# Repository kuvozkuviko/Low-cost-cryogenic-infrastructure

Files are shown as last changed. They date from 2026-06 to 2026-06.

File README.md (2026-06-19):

# Low-Cost Cryogenic Infrastructure

**EPFL Quantum Science and Engineering — Semester Project 2025–2026**  
**Author:** Andrés Quesnel González  
**Supervisor:** Dr. Gregor Taylor  
**Professor:** Prof. Edoardo Charbon

A low-cost cryogenic temperature readout system based on the Lake Shore Cryotronics DT-670 silicon diode and a thermal load measurement PCB for characterising the heat dissipation of 
cryogenic electronics.

---

## Overview

The system provides a stable 10 µA excitation current to a DT-670 silicon diode, reads the resulting voltage with a 24-bit ADC, converts it to temperature using the manufacturer's calibration 
table, and displays the result on two 7-segment displays. It was validated by monitoring the 4 K and 40 K stages of a Photon Spot Cryospot 4 over 24 hours.

The companion thermal load PCB uses a 1 kΩ thin-film resistor as a controllable heat source to establish a calibration curve of the cryocooler's cooling capacity as a function of temperature. 
This curve can then be used to quantify the thermal impact of any electronics placed inside the cryostat.

---

## Hardware

### Temperature Readout PCB

A custom PCB (60 × 35 mm) that drives a DT-670 silicon diode with a stable 10 µA constant current and reads its voltage response via a 24-bit ADS1220 ADC. 
The converted temperature is shown on two Grove 4-digit 7-segment displays connected to an Arduino UNO R4 WiFi.

**Key components:**

| Component | Part | Purpose |
|---|---|---|
| Voltage shunt regulator | LM4041-N ADJ | Precision 1.225 V reference |
| Transistor array | THAT 320S14-U | PNP current source with thermal compensation |
| Sensing resistor | TNPW0603 66.5 kΩ (0.1%, 10 PPM/°C) | Sets output current to 10 µA |
| ADC | ADS1220 | 24-bit, 596 nV resolution with 5 V reference |
| Voltage regulator | LM78L05 | 5 V regulated supply from 12 V lab rail |
| Microcontroller | Arduino UNO R4 WiFi | Reads ADC via SPI, drives displays |
| Displays | Grove 4-digit 7-segment (TM1637) | Shows temperature in kelvin |
| Connector | L17HTNES4R2C (Amphenol, right-angle DB-9) | Interfaces with cryostat wiring |

**Temperature resolution:**  
20 µK at 4 K · 259 µK at 300 K  
(24-bit ADC at 5 V reference, diode sensitivity from Table 2 of the report)

**Total system cost: CHF 273.26**

### Thermal Load PCB

A minimal PCB (16.24 × 15.26 mm) with a single 1 kΩ thin-film resistor, M3 mounting hole, and 4-pin through-hole connector for 4-wire SMU connection. 
It attaches to the PCB under test on one side and to a copper puck on the other.

---

## Getting Started

### Arduino Firmware

#### Requirements

- Arduino IDE 2.x or later
- Libraries (install via Library Manager):
  - `ADS1220_WE` by Wolfgang Ewald
  - `TM1637Display` by Avishay Orpaz

#### Wiring

| ADS1220 pin | Arduino UNO R4 pin |
|---|---|
| CS | 7 |
| DRDY | 6 |
| SCLK | 13 (SPI SCK) |
| DIN | 11 (SPI MOSI) |
| DOUT | 12 (SPI MISO) |

| Display | CLK | DIO |
|---|---|---|
| Sensor 1 (4 K stage) | 2 | 3 |
| Sensor 2 (40 K stage) | 4 | 5 |

---

### Python — Data Acquisition

Reads the Arduino's serial output and saves it to a CSV file.

#### Requirements

```
pip install pyserial
```

#### Usage

```bash
python code/data_Sidiode.py --port /dev/ttyUSB0 --output CSVs/andres_2_06_log_temperaturereadout.csv
```

Arguments:
- `--port`: Serial port the Arduino is connected to (e.g. `COM3` on Windows, `/dev/ttyACM0` on Linux)
- `--output`: Path to the output CSV file
- `--baud`: Baud rate (default: 9600)

Output CSV format:
```
time_ms, T1_K, T2_K
1204, 3.214823, 32.771456
...
```

---

### Python — Analysis and Plotting

#### Requirements

```
pip install numpy pandas matplotlib scipy
```

#### Temperature curves (RT measurement)

```bash
python Code/Sidiode_plot.py --input CSVs/andres_2_06_log_temperaturereadout.csv
```

Produces a plot of temperature vs time for both stages, equivalent to Figure 8 in the report.

#### Thermal load calibration curves

```bash
python python/analysis/plot_heatload.py \
    --smooth data/heatload_smooth.csv \
    --coarse data/heatload_coarse.csv
```

Produces the three-panel plot (Figure 9 in the report): measured power vs temperature, power difference vs temperature, and cryogenic resistance R(T).

Input CSV format (from the AQUA lab measurement script):
```
Time [s], T [K], Current [A], Voltage [V], Power [mW], Resistance [Ohm]
```

---

## Mechanical

`Thermal Load/CopperPuck-Body.step` is the STEP file for the copper puck used to absorb heat on the back side of the thermal load PCB when it is mounted inside the cryostat. Import into FreeCAD, Fusion 360, or any STEP-compatible CAD tool.

---

## SPICE Simulation

`Temperature Readout/Simu_SiDiode670.asc` is the LTspice XVII simulation of the LM4041-N ADJ constant current source. It was used to verify that the output current is independent of the biasing current and to compare the performance of the 120 kΩ and 122.5 kΩ sensing resistor values.

Open with LTspice XVII (free, from Analog Devices).

---

## Bill of Materials

| Item | Cost (CHF) |
|---|---|
| PCB fabrication (Eurocircuits) | 200.00 |
| Arduino UNO R4 WiFi | 23.70 |
| 2× Grove 7-segment displays | 13.77 |
| Display cables | 1.10 |
| Stripboard | 5.10 |
| Aluminium enclosure (Hammond) | 25.30 |
| **Total** | **269.97** |

---

## Known Issues and Future Work

- The 66.5 kΩ sensing resistor was hand-soldered to replace the original 120 kΩ value. The solder joints are visually imperfect and the output current may deviate slightly from the target 10 µA, introducing a small systematic temperature offset.
- The DB-9 connector pin ordering on the original PCB was incorrect and was corrected with a wired adapter. A future PCB revision should use the correct pinout directly.
- The ADS1220 is configured with a 5 V external reference (REFP0 = 5 V), giving 596 nV resolution. Using the internal 2.048 V reference would improve resolution to 244 nV, since the DT-670 voltage never exceeds 1.644 V.
- Two-minute dwell times between thermal load current steps were insufficient for full thermal equilibration. Future measurements should use at least 5 minutes per step.
- The thermal load calibration was performed with the PCB under test powered off. A future measurement with the PCB powered will yield its actual heat dissipation.

---

## Related Files

The full semester project report (`TP4_spring_2026.pdf`) is included at the root of this repository and contains the full circuit analysis, component selection rationale, measurement results, and discussion.

---

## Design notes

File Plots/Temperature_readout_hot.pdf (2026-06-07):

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

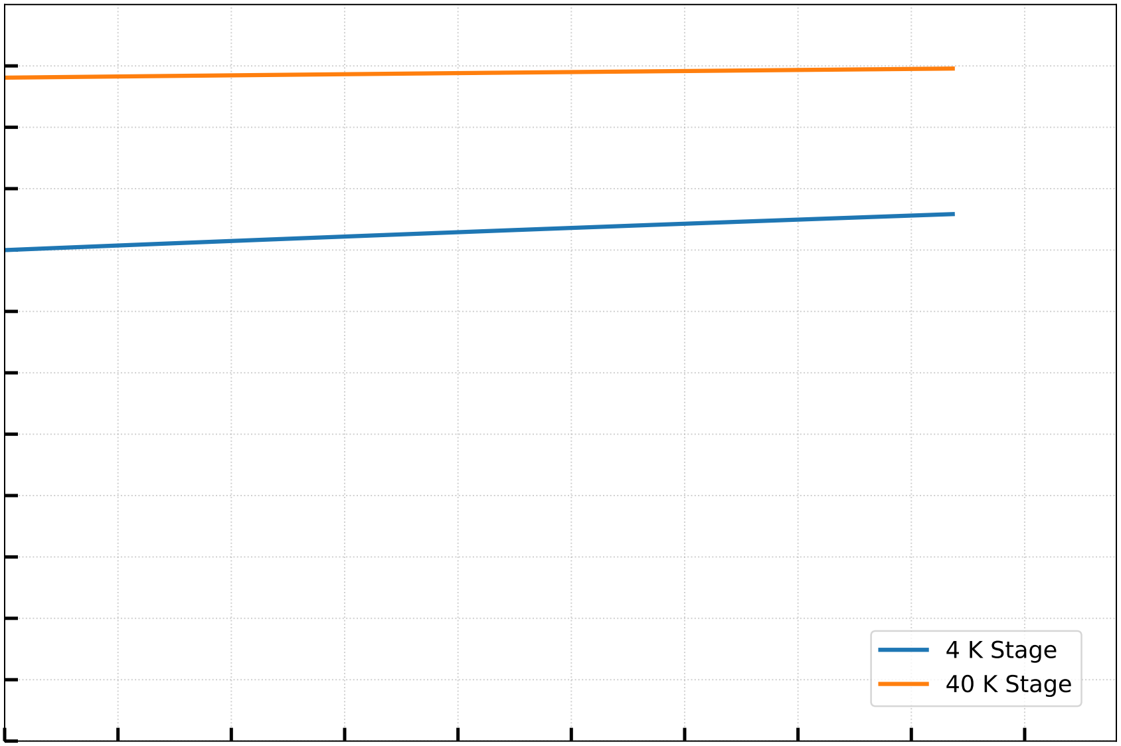
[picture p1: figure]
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

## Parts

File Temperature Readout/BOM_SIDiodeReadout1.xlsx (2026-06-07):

Qty | Reference Designators | Value | Package | Manufacturer | MPN | Placed
2 | U1, U2 | LM4041AIM3-1.2 | SOT-23 | Texas Instruments | LM4041AIM3-1.2 | YES
1 | U3 | LM78L05ACM/NOPB | SOIC-8 | Texas Instruments | LM78L05ACM/NOPB | YES
1 | IC1 | 320S14-U | SOIC-14 | THAT Corporation | 320S14-U | YES
1 | IC2 | ADS1220IPW | TSSOP-16 | Texas Instruments | ADS1220IPW | YES
2 | Rka1, Rka2 | 21k | R0603 | Vishay | TNPW060321K0BYEN | YES
2 | Rsense1, Rsense2 | 120k | R0603 | Vishay | TNPW0603120KBYEN | YES
10 | Rain0, Rain1, Rain2, Rain3, Rcs1, Rdin1, Rdout1, Rrefn0, Rrefp0, Rsclk1 | 47R | R0603 | Yageo | RT0603BRC0747RL | YES
6 | Cain0, Cain1, Cain2, Cain3, Crefn0, Crefp0 | 10nF | C0603 | KYOCERA AVX | 06033A103JAT2A | YES
3 | Cain0/1, Cain2/3, Crefn/p0 | 100nF | C1206 | Yageo | C1206C104J3GAC | YES
2 | Cavdd1, Cdvdd1 | 100nF | C0603 | Yageo | CC0603KRX7R8BB104 | YES
2 | Cpin1, Cpout1 | 1uF | C0603 | Yageo | CC0603KPX7R8BB105 | YES
1 | J1 | HTSW-106-07-F-S | THT 2.54mm | Samtec | HTSW-106-07-F-S | YES
1 | Pin1 | HTSW-102-07-L-S | THT 2.54mm | Samtec | HTSW-102-07-L-S | YES
1 | Pout1 | L17HTNES4R2C | D-Sub | Amphenol | L17HTNES4R2C | YES
2 | Rsense1, Rsense2 (the new ones) | 66k5 | R0603 | TE Connectivity / Holsworthy | RN73C1J66K5BTDF | NO

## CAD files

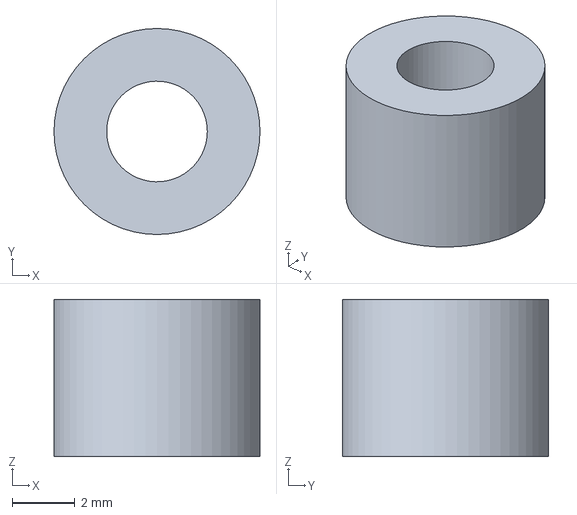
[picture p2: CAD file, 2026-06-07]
Thermal Load/CopperPuck.FCStd
6.55 x 6.55 x 5.00 mm

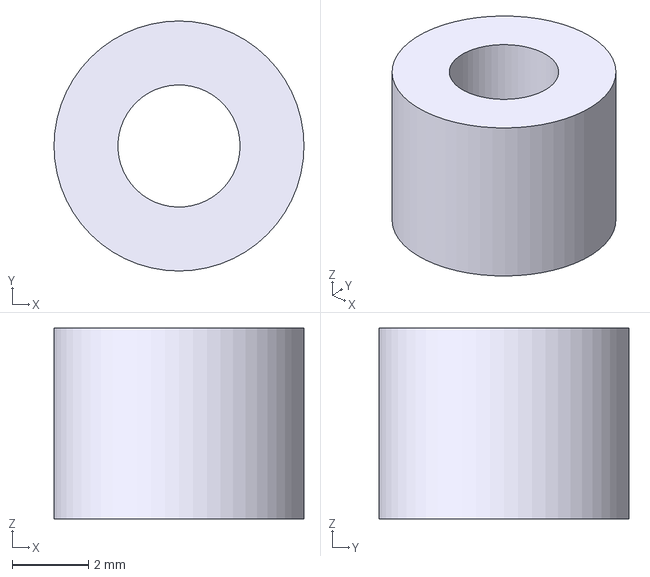
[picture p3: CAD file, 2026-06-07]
Thermal Load/CopperPuck-Body.step
6.55 x 6.55 x 5.00 mm

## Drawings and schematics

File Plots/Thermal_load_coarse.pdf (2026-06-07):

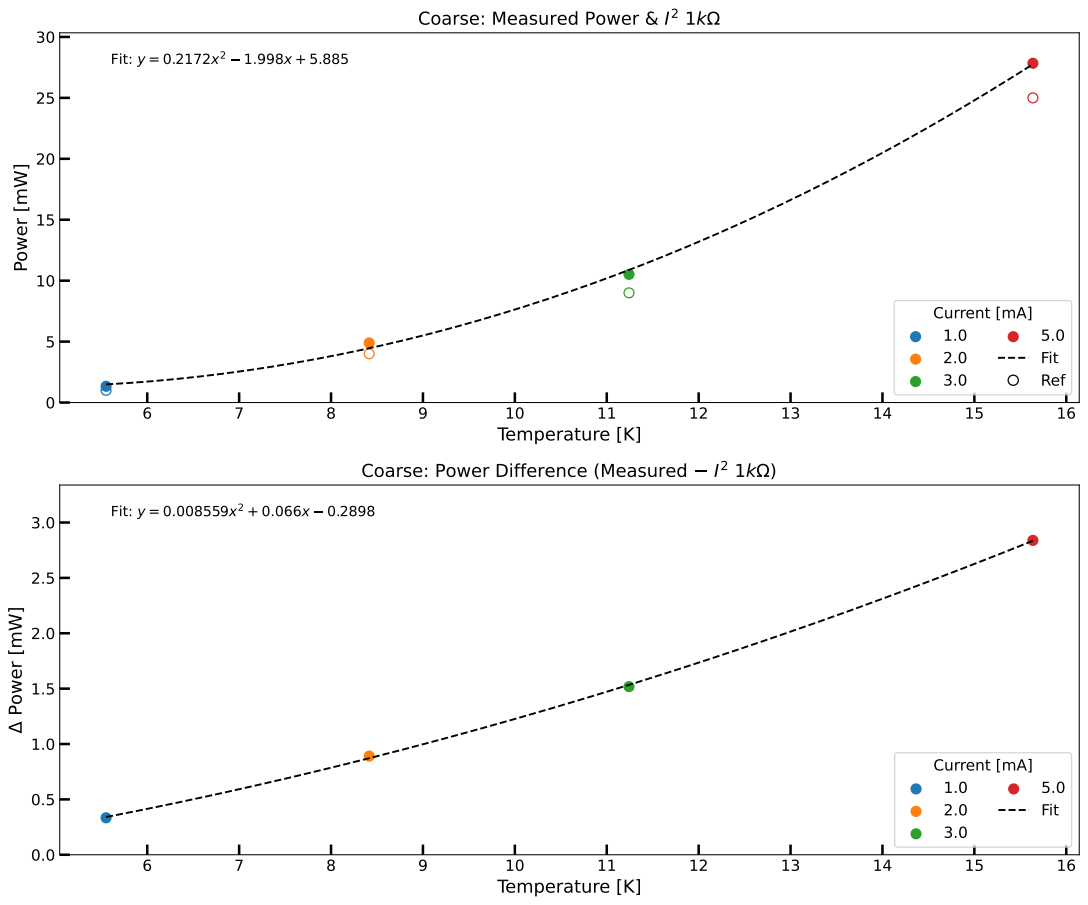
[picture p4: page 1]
Temperature [K]; Power [mW]; Fit: y = 0.2172x; Current [mA] 1.0 2.0 3.0; 5.0 Fit Ref; Fit: y = 0.008559x; Coarse: Power Difference (Measured; 5.0 Fit

Coarse: Measured Power & I

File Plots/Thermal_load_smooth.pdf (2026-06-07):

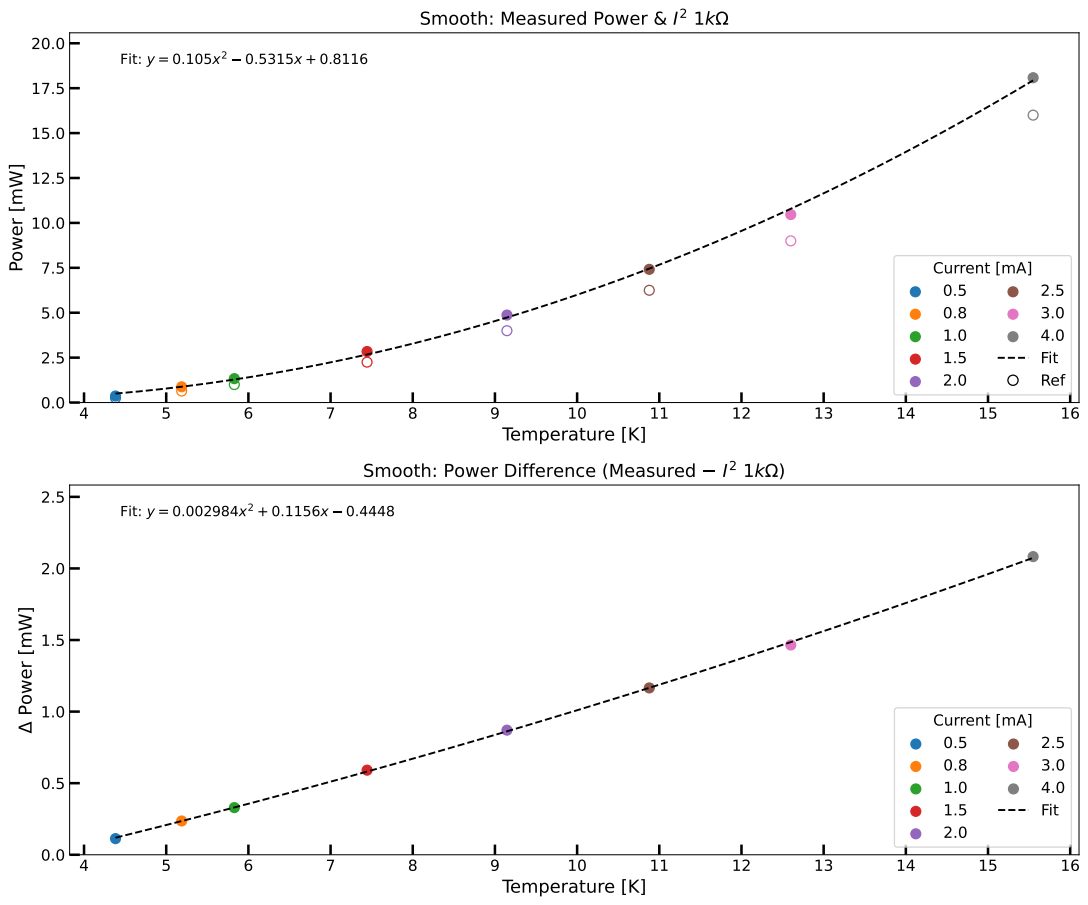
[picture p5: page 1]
Temperature [K]; Power [mW]; Fit: y = 0.105x; Current [mA] 0.5 0.8 1.0 1.5 2.0; 2.5 3.0 4.0 Fit Ref; Fit: y = 0.002984x; Smooth: Power Difference (Measured; 2.5 3.0 4.0 Fit

Smooth: Measured Power & I

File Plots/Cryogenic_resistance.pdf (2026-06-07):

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

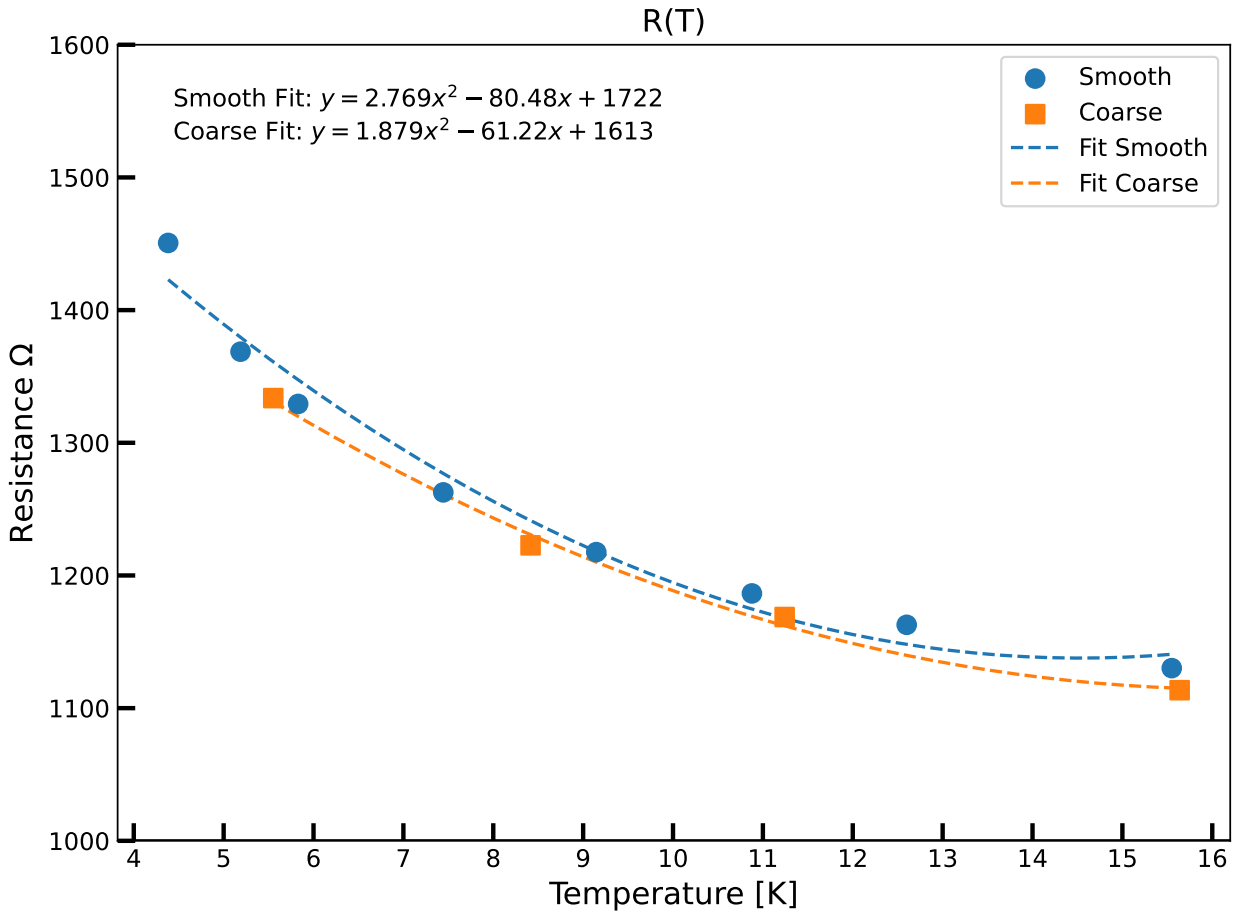
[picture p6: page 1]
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

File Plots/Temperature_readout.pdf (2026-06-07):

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

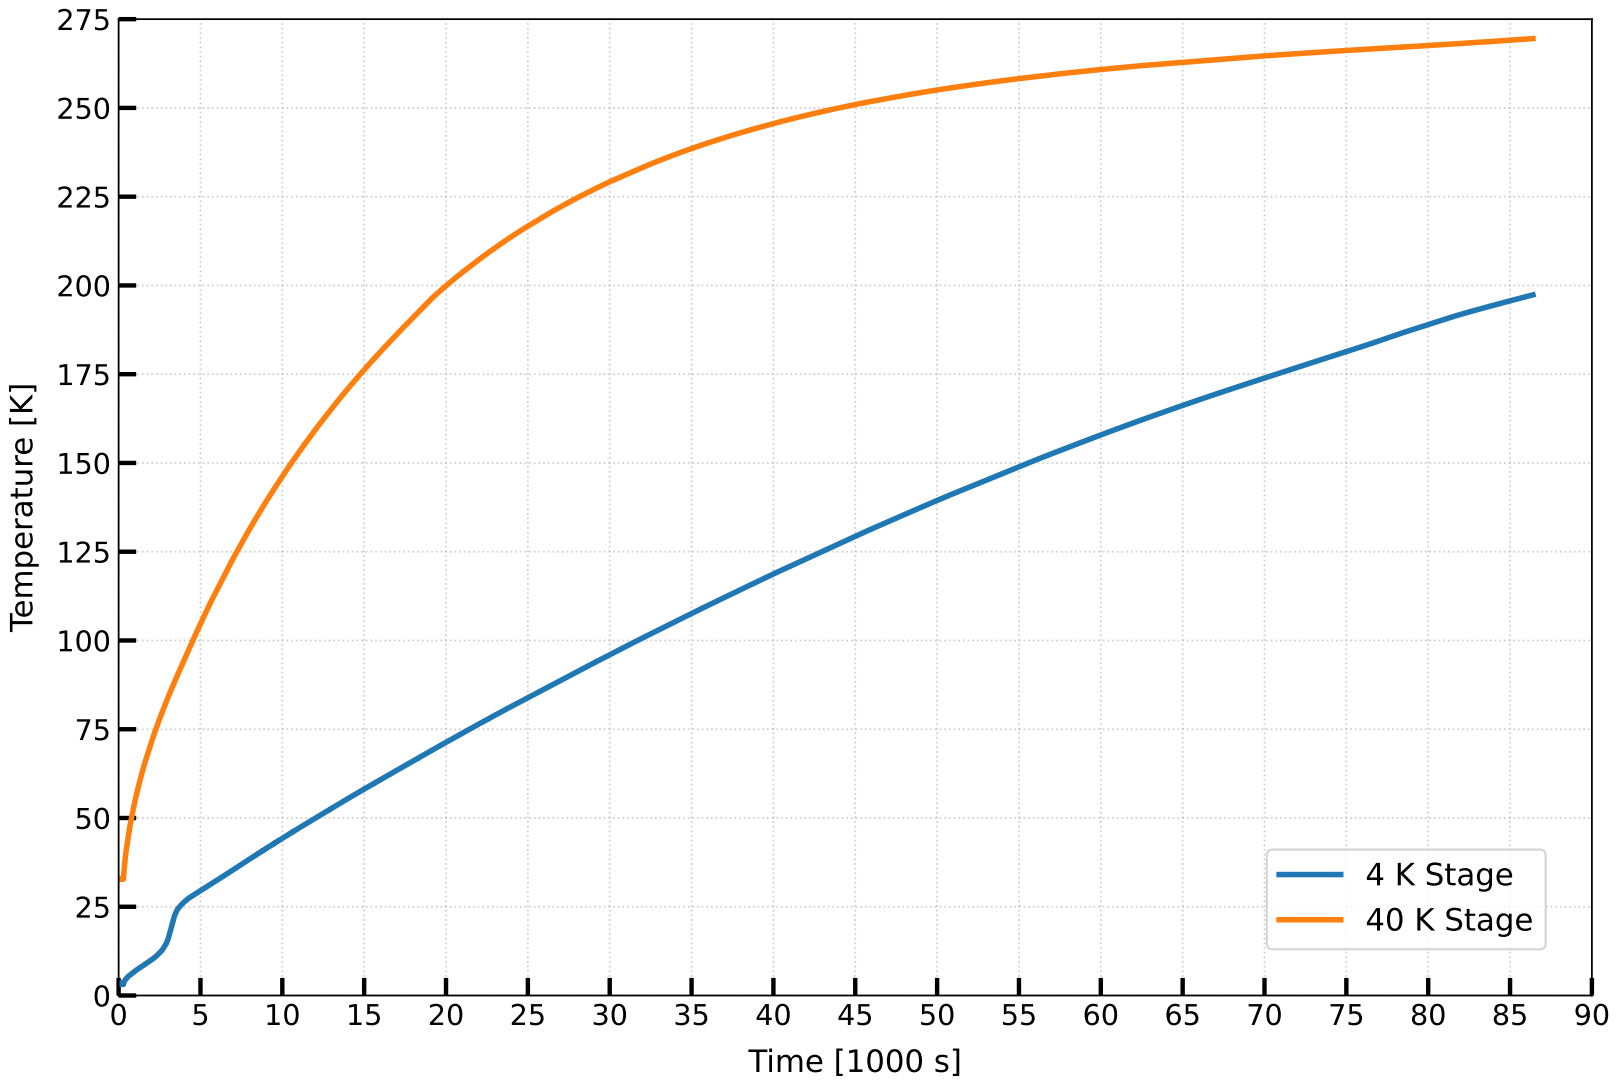
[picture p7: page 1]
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

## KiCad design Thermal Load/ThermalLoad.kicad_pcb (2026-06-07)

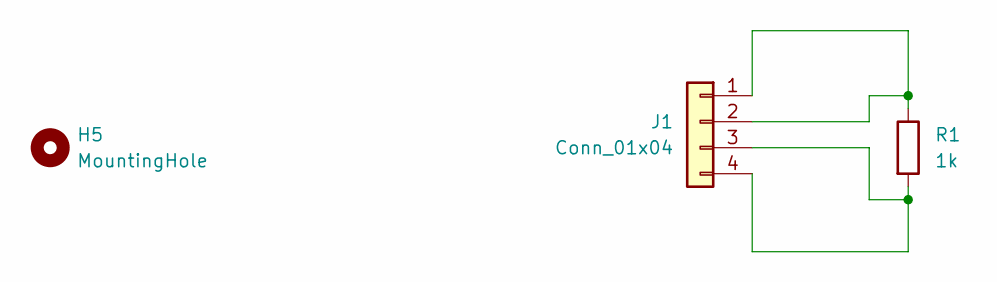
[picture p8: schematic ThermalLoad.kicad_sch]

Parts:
H5: MountingHole; MountingHole_3.2mm_M3
J1: Conn_01x04; PinHeader_1x04_P2.54mm_Vertical
R1: 1k; R_0603_1608Metric

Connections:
unnamed: J1.1, J1.2, R1.1
unnamed: J1.3, J1.4, R1.2

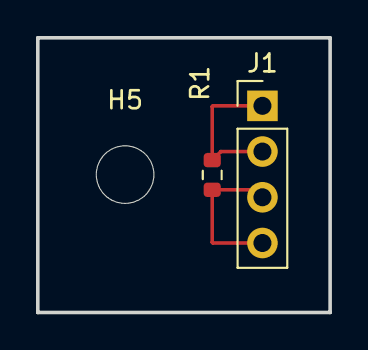
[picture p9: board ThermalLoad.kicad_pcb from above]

Board: 2 copper layers, 16.2 x 15.3 mm, 3 parts (0 on the bottom side), 2 nets.

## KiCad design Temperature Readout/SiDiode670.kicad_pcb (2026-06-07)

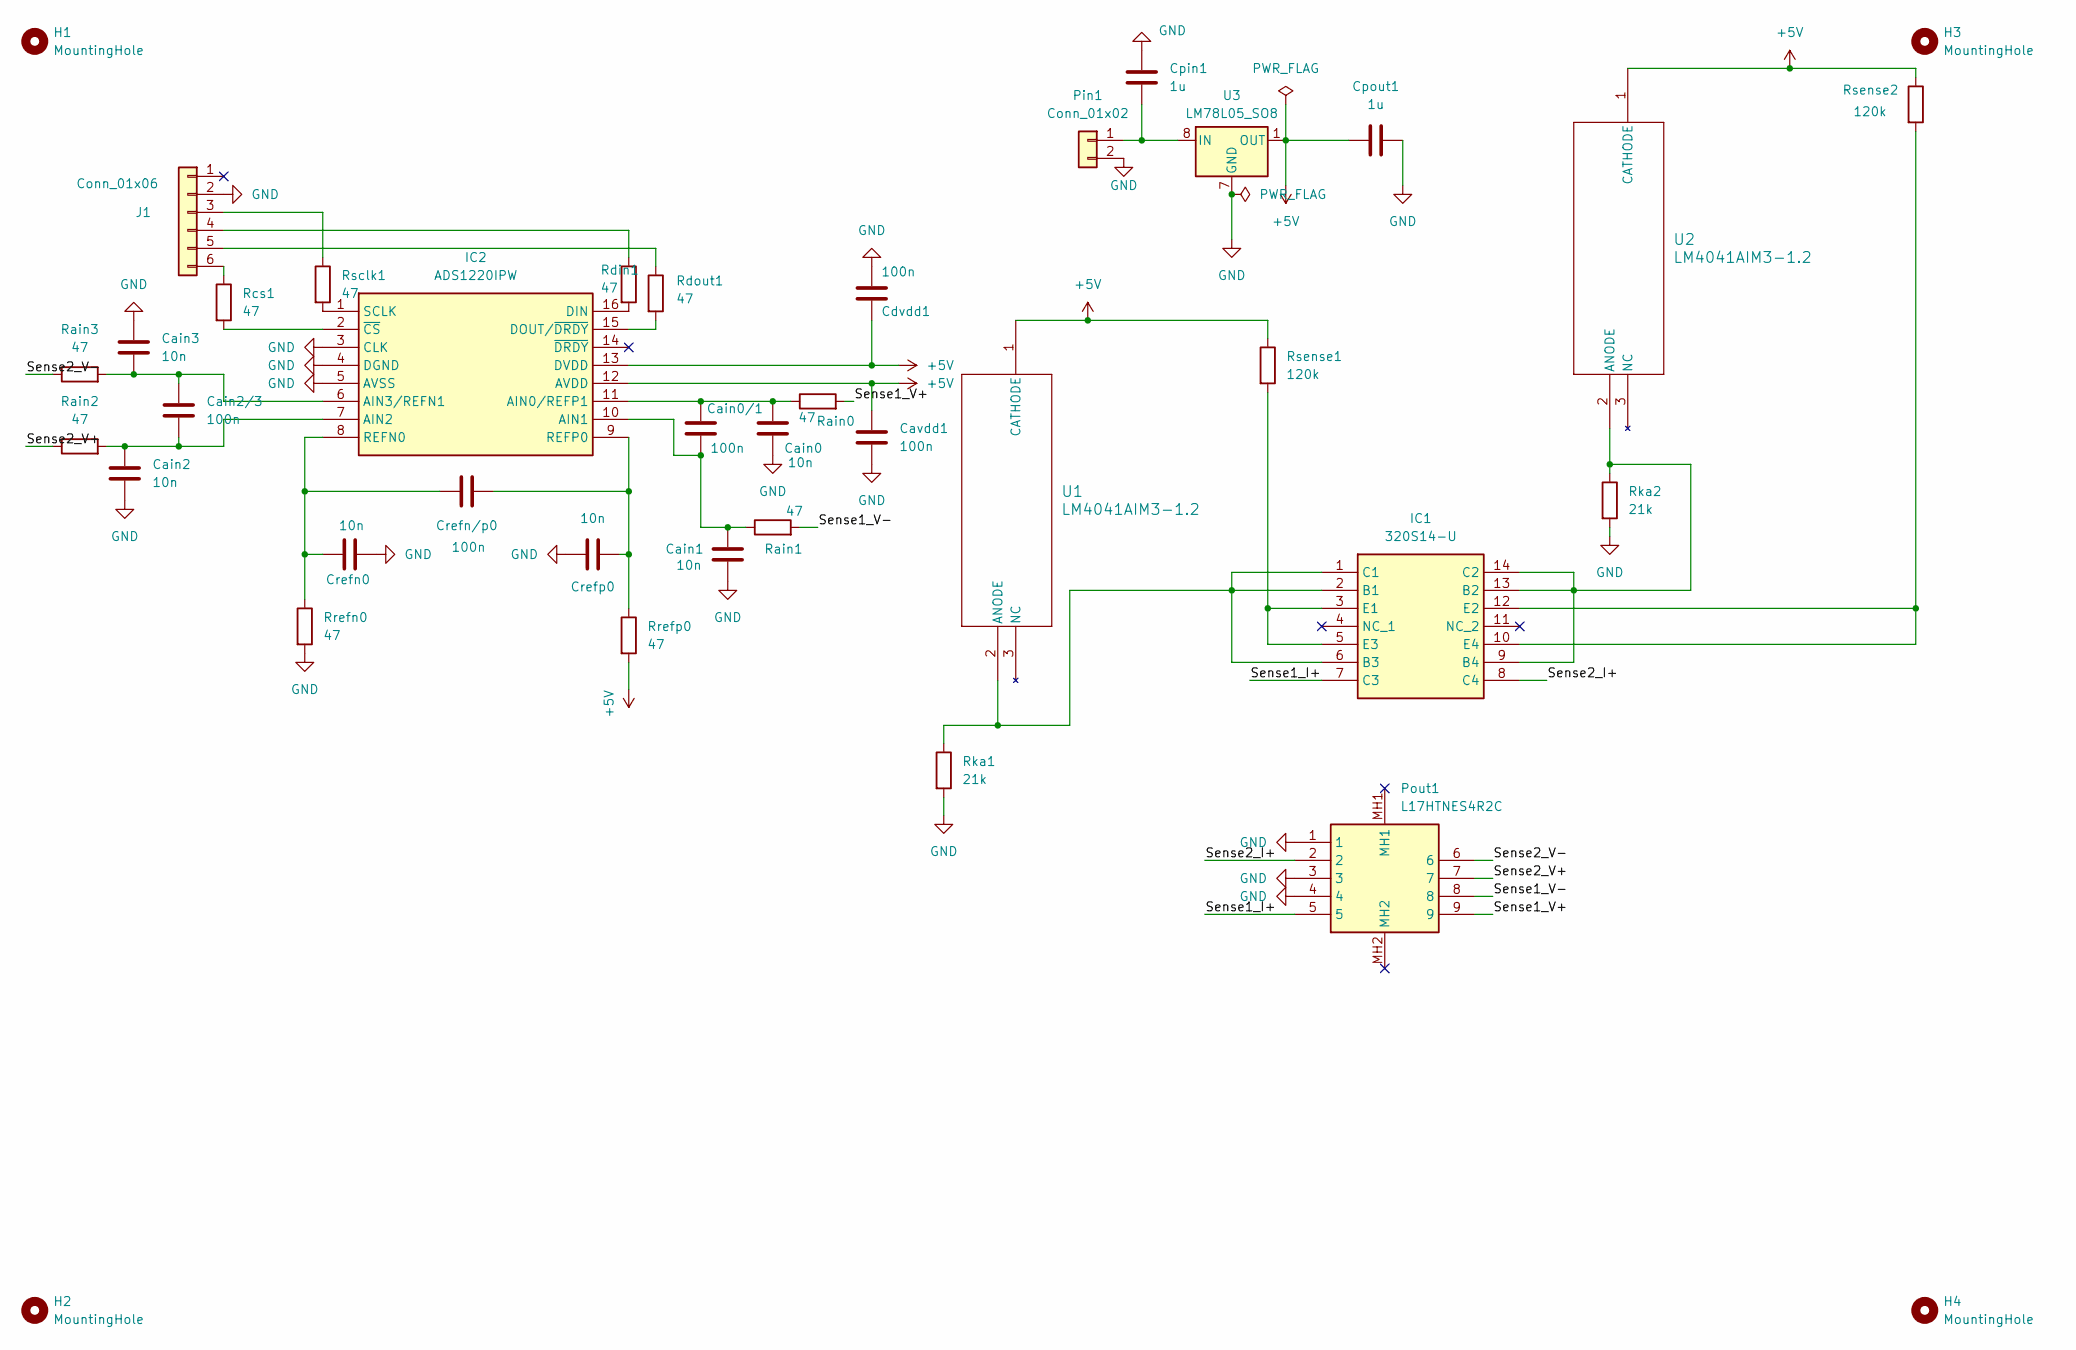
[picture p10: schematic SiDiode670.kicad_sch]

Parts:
Cain0, Cain1, Cain2, Cain3: 10n; C_0603_1608Metric
Cain0/1, Cain2/3: 100n; C_1206_3216Metric
Cavdd1: 100n; C_0603_1608Metric
Cdvdd1: 100n; C_0603_1608Metric
Cpin1: 1u; C_0603_1608Metric
Cpout1: 1u; C_0603_1608Metric
Crefn0: 10n; C_0603_1608Metric
Crefn/p0: 100n; C_1206_3216Metric
Crefp0: 10n; C_0603_1608Metric
H1, H2, H3, H4: MountingHole; MountingHole_3.2mm_M3
IC1: 320S14-U; SOIC127P602X175-14N; Mouser Part Number 887-320S14-U
IC2: ADS1220IPW; SOP65P640X120-16N; Mouser Part Number 595-ADS1220IPW
J1: Conn_01x06; PinHeader_1x06_P2.54mm_Vertical
Pin1: Conn_01x02; PinHeader_1x02_P2.54mm_Vertical
Pout1: L17HTNES4R2C; Mouser Part Number 523-L17HTNES4R2C
Rain0, Rain1, Rain2, Rain3: 47; R_0603_1608Metric
Rcs1: 47; R_0603_1608Metric
Rdin1: 47; R_0603_1608Metric
Rdout1: 47; R_0603_1608Metric
Rka1, Rka2: 21k; R_0603_1608Metric
Rrefn0: 47; R_0603_1608Metric
Rrefp0: 47; R_0603_1608Metric
Rsclk1: 47; R_0603_1608Metric
Rsense1, Rsense2: 120k; R_0603_1608Metric
U1, U2: LM4041AIM3-1.2; SOT-23_DBZ_TEX-L
U3: LM78L05_SO8; SOIC-8_3.9x4.9mm_P1.27mm

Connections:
+5V: Cavdd1.1, Cdvdd1.1, Cpout1.1, IC2.12 (AVDD), IC2.13 (DVDD), Rrefp0.2, Rsense1.1, Rsense2.1, U1.1 (CATHODE), U2.1 (CATHODE), U3.1 (OUT)
/Sense1_I+: IC1.7 (C3), Pout1.5
/Sense1_V+: Pout1.9, Rain0.2
/Sense1_V-: Pout1.8, Rain1.2
/Sense2_I+: IC1.8 (C4), Pout1.2
/Sense2_V+: Pout1.7, Rain2.1
/Sense2_V-: Pout1.6, Rain3.1
GND: Cain0.2, Cain1.2, Cain2.2, Cain3.1, Cavdd1.2, Cdvdd1.2, Cpin1.1, Cpout1.2, Crefn0.2, Crefp0.1, IC2.3 (CLK), IC2.4 (DGND), IC2.5 (AVSS), J1.2, Pin1.2, Pout1.1, Pout1.3, Pout1.4, Rka1.2, Rka2.2, Rrefn0.2, U3.2 (GND), U3.3 (GND), U3.6 (GND), U3.7 (GND)
unnamed: IC1.1 (C1), IC1.2 (B1), IC1.6 (B3), Rka1.1, U1.2 (ANODE)
unnamed: IC1.9 (B4), IC1.13 (B2), IC1.14 (C2), Rka2.1, U2.2 (ANODE)
unnamed: IC1.3 (E1), IC1.5 (E3), Rsense1.2
unnamed: IC1.10 (E4), IC1.12 (E2), Rsense2.2
unnamed: Cain0.1, Cain0/1.1, IC2.11 (AIN0/REFP1), Rain0.1
unnamed: Cain0/1.2, Cain1.1, IC2.10 (AIN1), Rain1.1
unnamed: Cain2.1, Cain2/3.2, IC2.7 (AIN2), Rain2.2
unnamed: Cain2/3.1, Cain3.2, IC2.6 (AIN3/REFN1), Rain3.2
unnamed: IC2.16 (DIN), Rdin1.2
unnamed: IC2.15 (DOUT/~DRDY), Rdout1.2
unnamed: Crefn0.1, Crefn/p0.1, IC2.8 (REFN0), Rrefn0.1
unnamed: Crefn/p0.2, Crefp0.2, IC2.9 (REFP0), Rrefp0.1
unnamed: IC2.1 (SCLK), Rsclk1.2
unnamed: IC2.2 (~CS), Rcs1.2
unnamed: J1.3, Rsclk1.1
unnamed: J1.4, Rdin1.1
unnamed: J1.5, Rdout1.1
unnamed: J1.6, Rcs1.1
unnamed: Cpin1.2, Pin1.1, U3.8 (IN)

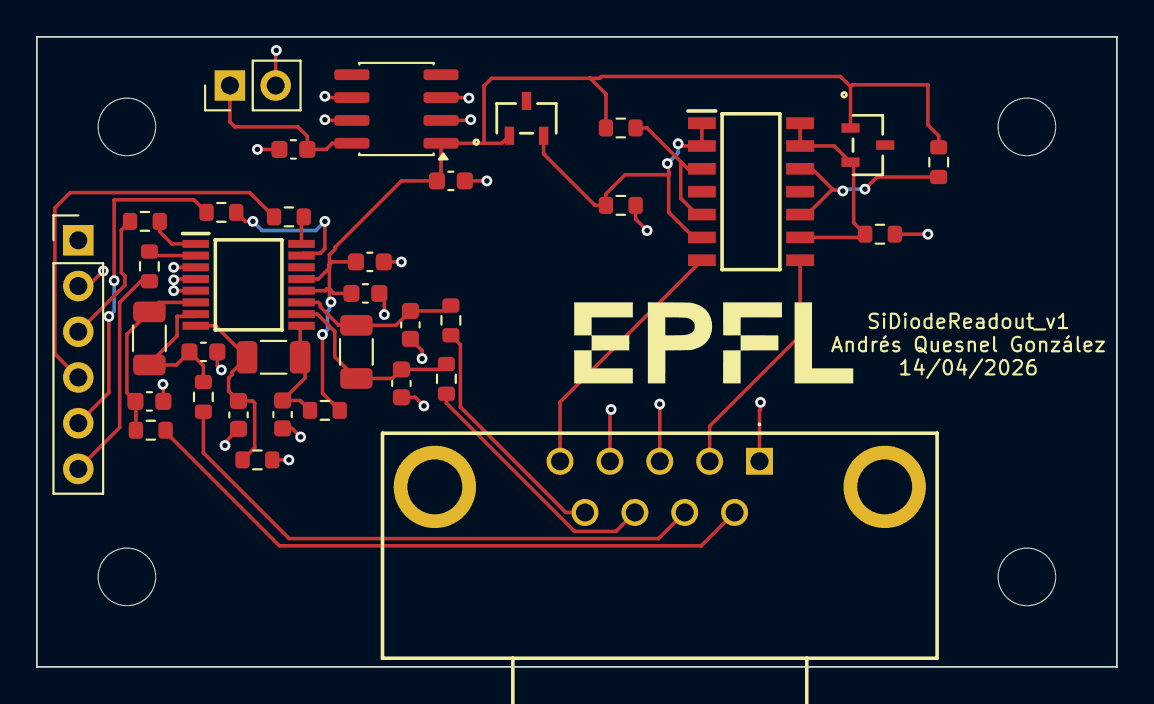
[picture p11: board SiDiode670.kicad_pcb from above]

Board: 2 copper layers, 60.0 x 35.0 mm, 39 parts (0 on the bottom side), 27 nets.

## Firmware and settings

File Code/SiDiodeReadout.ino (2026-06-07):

/*
 *  Hardware:
 *    - ADS1220 24-bit ADC, connected via SPI (J1 on PCB)
 *    - 2× TM1637 4-digit 7-segment displays
 *    - 2× Lakeshore DT-670 silicon diodes via DE-9 connectors
 *      (Pout1: Sense1_V+, Sense1_V-, Sense2_V+, Sense2_V-, GND)
 *
 *  Required libraries:
 *    - "ADS1220_WE" by Wolfgang Ewald
 *    - "TM1637Display" by Avishay Orpaz
 *
 *  Pin assignments:
 *    ADS1220 CS   → Arduino pin 7
 *    ADS1220 DRDY → Arduino pin 6
 *    ADS1220 SCLK → Arduino pin 13 (hardware SPI SCK)
 *    ADS1220 DIN  → Arduino pin 11 (hardware SPI MOSI)
 *    ADS1220 DOUT → Arduino pin 12 (hardware SPI MISO)
 *
 *    Display 1 CLK → Arduino pin 2
 *    Display 1 DIO → Arduino pin 3
 *    Display 2 CLK → Arduino pin 4
 *    Display 2 DIO → Arduino pin 5
 *
 *  ADC channel assignment (verify against schematic):
 *    Sensor 1: AIN0 (Sense1_V+) vs AIN1 (Sense1_V−)  — differential
 *    Sensor 2: AIN2 (Sense2_V+) vs AIN3 (Sense2_V−)  — differential
 *
 *  Display format (Kelvin):
 *    T ≥ 100 K  →  " 300"   (integer, no decimal)
 *    10 ≤ T < 100 K  →  "77.35"   (2 decimal place)
 *    T < 10 K   →  " 4.22"   (2 decimal places)
 *    Out of range   →  "Err "
 */

#include <ADS1220_WE.h>
#include <SPI.h>
#include <TM1637Display.h>
#include <avr/pgmspace.h>

// Pin definitions

#define ADS1220_CS_PIN    7   // ADS1220 chip select (active low)
#define ADS1220_DRDY_PIN 6   // ADS1220 data ready (active low)

#define DISP1_CLK  2          // TM1637 display 1 — Sensor 1
#define DISP1_DIO  3
#define DISP2_CLK  4          // TM1637 display 2 — Sensor 2
#define DISP2_DIO  5

struct TempPoint {
  float voltage;  // Volts
  float temp;     // Kelvin
};

unsigned long time_ms;

// !!!Calibration Table!!!
const TempPoint dt670_table[] PROGMEM = {
  {1.644290f, 1.4f},
  {1.642990f, 1.5f},
  {1.641570f, 1.6f},
  {1.640030f, 1.7f},
  {1.638370f, 1.8f},
  {1.636600f, 1.9f},
  {1.634720f, 2.0f},
  {1.632740f, 2.1f},
  {1.630670f, 2.2f},
  {1.628520f, 2.3f},
  {1.626290f, 2.4f},
  {1.624000f, 2.5f},
  {1.621660f, 2.6f},
  {1.619280f, 2.7f},
  {1.616870f, 2.8f},
  {1.614450f, 2.9f},
  {1.612000f, 3.0f},
  {1.609510f, 3.1f},
  {1.606970f, 3.2f},
  {1.604380f, 3.3f},
  {1.601730f, 3.4f},
  {1.599020f, 3.5f},
  {1.596260f, 3.6f},
  {1.593440f, 3.7f},
  {1.590570f, 3.8f},
  {1.587640f, 3.9f},
  {1.584650f, 4.0f},
  {1.578480f, 4.2f},
  {1.572020f, 4.4f},
  {1.565330f, 4.6f},
  {1.558450f, 4.8f},
  {1.551450f, 5.0f},
  {1.544360f, 5.2f},
  {1.537210f, 5.4f},
  {1.530000f, 5.6f},
  {1.522730f, 5.8f},
  {1.515410f, 6.0f},
  {1.496980f, 6.5f},
  {1.478680f, 7.0f},
  {1.460860f, 7.5f},
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
};

const int TABLE_SIZE = sizeof(dt670_table) / sizeof(TempPoint);

// !!!Segment patterns!!!

// "Err " — shown when voltage is outside the calibrated range
const uint8_t SEG_ERR[] = {
  SEG_A | SEG_D | SEG_E | SEG_F | SEG_G,  // E
  SEG_E | SEG_G,                           // r
  SEG_E | SEG_G,                           // r
  0x00                                     // (blank)
};

// !!!Object instantiation!!!
ADS1220_WE ads = ADS1220_WE(ADS1220_CS_PIN, ADS1220_DRDY_PIN);
TM1637Display disp1(DISP1_CLK, DISP1_DIO);
TM1637Display disp2(DISP2_CLK, DISP2_DIO);

// !!!Voltage to Temperature conversion!!!

// Linear interpolation between the two nearest table entries.
// Returns temperature in Kelvin, or -1.0 if out of range.
//
// The table is sorted by decreasing voltage, so we search for
// the interval where:  voltage[i] >= measured_V >= voltage[i+1]

float voltageToKelvin(float voltage_V) {
  // Read bounds from PROGMEM
  float v_max = pgm_read_float(&(dt670_table[0].voltage));
  float v_min = pgm_read_float(&(dt670_table[TABLE_SIZE - 1].voltage));

  if (voltage_V > v_max || voltage_V < v_min) {
    return -1.0f;  // voltage out of calibrated range
  }

  for (int i = 0; i < TABLE_SIZE - 1; i++) {
    float v_hi = pgm_read_float(&(dt670_table[i].voltage));
    float v_lo = pgm_read_float(&(dt670_table[i + 1].voltage));

    if (voltage_V <= v_hi && voltage_V >= v_lo) {
      float T_lo = pgm_read_float(&(dt670_table[i].temp));
      float T_hi = pgm_read_float(&(dt670_table[i + 1].temp));

      // Linear interpolation:
      // frac = 0 → v_hi → T_lo (lower temperature)
      // frac = 1 → v_lo → T_hi (higher temperature)
      float frac = (v_hi - voltage_V) / (v_hi - v_lo);
      return T_lo + frac * (T_hi - T_lo);
    }
  }

  return -1.0f;  // should never be reached
}

// !!!Display temperature in Kelvin on a TM1637!!!
//
// TM1637Display dots parameter (avishorp library):
//   0x80 → dot after digit 0 (leftmost)
//   0x40 → dot after digit 1  ← colon on clock displays
//   0x20 → dot after digit 2
//   0x10 → dot after digit 3 (rightmost)
//
// With 0x20 and right-justified numbers:
//   num=773 → [' ']['7']['7']['3'] + dot at pos 2 → " 77.3"
//   num=42  → [' '][' ']['4']['2'] + dot at pos 2 → "  4.2"
//   num=300 → [' ']['3']['0']['0'] no dot          → " 300"

void displayKelvin(TM1637Display& disp, float tempK) {
  if (tempK < 0.0f) {
    // Show "Err " – setSegments expects length and position
    disp.setSegments(SEG_ERR, 4, 0);
    return;
  }

  // Temperatures ≥ 100 K → integer only (no decimal, no colon)
  if (tempK >= 100.0f) {
    int integerPart = (int)(tempK + 0.5f);
    disp.showNumberDec(integerPart, false);  // false = no leading zeros
    return;
  }

  // For T < 100 K: show "AB:CD" using colon between digits 1 & 2
  // Round to two fractional digits, then multiply by 100
  int value = (int)(tempK * 100.0f + 0.5f);
  
  // Display as 4‑digit number with leading zeros, colon mask 0x60
  // 0x60 lights both colon dots (between digit1 and digit2)
  disp.showNumberDecEx(value, 0x60, true, 4, 0);
}


// !!!Setup!!!

void setup() {
  Serial.begin(9600);
  Serial.println(F("DT-670 Cryogenic Temperature Readout"));
  Serial.println(F("EPFL SiDiodeReadout_v1"));
  
  // Initialise TM1637 displays
  disp1.setBrightness(0x0F); // maximum brightness
  disp2.setBrightness(0x0F);
  
  // Power-on self-test: all segments on for 1 second
  disp1.showNumberDecEx(8888, 0xFF, true);
  disp2.showNumberDecEx(8888, 0xFF, true);
  delay(1000);
  disp1.clear();
  disp2.clear();

  // Initialise ADS1220
  if (!ads.init()) {
    Serial.println(F("ERROR: ADS1220 not responding. Check SPI wiring!"));
    disp1.setSegments(SEG_ERR);
    disp2.setSegments(SEG_ERR);
    while (1); // halt execution
  }
  
  // !!!ADS1220 configuration!!!
  //
  // PGA bypassed:
  //   DT-670 output spans 0.09 V–1.64 V, well within the 2.048 V
  //   internal reference. Gain = 1 is sufficient; no amplification needed.

  ads.bypassPGA(true);

  // Data rate: 20 SPS
  //   Lowest available rate → best noise performance.
  //   The ADS1220 digital filter simultaneously rejects 50 Hz and 60 Hz
  //   at 20 SPS — ideal for a rack instrument in a lab environment.
  ads.setDataRate(ADS1220_DR_LVL_0);

  // Conversion mode: single-shot
  //   Triggered on demand before each reading. Saves power and avoids
  //   noise from continuous conversion between readings.
  ads.setConversionMode(ADS1220_SINGLE_SHOT);

  Serial.println(F("ADS1220 initialised. Starting readout."));
  Serial.println(F("--------------------------------------------"));
  Serial.println(F("Sensor | Voltage (V) | Temperature (K)"));
  Serial.println(F("--------------------------------------------"));
}

// !!!Main loop!!!

void loop() {

  // Sensor 1: AIN0 (+) vs AIN1 (−), differential
  ads.setCompareChannels(ADS1220_MUX_0_1);
  float voltage1_V = ads.getVoltage_mV() / 1000.0f;
  float temp1_K    = voltageToKelvin(voltage1_V);

  // Sensor 2: AIN2 (+) vs AIN3 (−), differential
  ads.setCompareChannels(ADS1220_MUX_2_3);
  float voltage2_V = ads.getVoltage_mV() / 1000.0f;
  float temp2_K    = voltageToKelvin(voltage2_V);

  // Update 7-segment displays
  displayKelvin(disp1, temp1_K);
  displayKelvin(disp2, temp2_K);

// !!!Outputting live data into terminal when testing!!!
//  Serial.print(F("  S1   | "));
//  Serial.print(voltage1_V, 6);
//  Serial.print(F(" V  | "));
//  if (temp1_K < 0.0f) Serial.println(F("OUT OF RANGE"));
//  else { Serial.print(temp1_K, 3); Serial.println(F(" K")); }

//   Serial.print(F("  S2   | "));
//   Serial.print(voltage2_V, 6);
 //  Serial.print(F(" V  | "));
 //  if (temp2_K < 0.0f) Serial.println(F("OUT OF RANGE"));
  // else { Serial.print(temp2_K, 3); Serial.println(F(" K")); }


    time_ms = millis();
    Serial.print(time_ms);
    Serial.print(",");

    if (temp1_K < 0.0f) Serial.print(-999.0);
    else Serial.print(temp1_K, 6);

    Serial.print(",");

    if (temp2_K < 0.0f) Serial.print(-999.0);
    else Serial.print(temp2_K, 6);

    Serial.println();

  // Take a measurement every 10 seconds
  delay(500);
}

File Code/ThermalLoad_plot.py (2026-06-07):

"""
Cryogenic Heat Load and Resistance Characterization Plotting Script
Processes and compares thermal load data from two experimental runs (coarse and smooth).
Calculates and contrasts measured electrical power dissipation against room 
temperature values and models the data using quadratic polynomial regressions.
"""

import pandas as pd
import numpy as np
import matplotlib.pyplot as plt
from matplotlib.lines import Line2D

# Load separate experimental datasets: a coarse sweeping scan and a high-resolution smooth scan
df_coarse = pd.read_csv("andres_2_06_log_heatload_coarse.csv")
df_smooth = pd.read_csv("andres_2_06_log_heatload.csv")
R = 1e3 # Value of the resistor on the PCB

# Calculate the reference power dissipation ($P = I^2 R$) in milliwatts
df_coarse["I2R_mW"] = (df_coarse["Current [A]"]**2) * R * 1000
df_smooth["I2R_mW"]  = (df_smooth["Current [A]"]**2) * R * 1000

# Find the difference between room and cryogenic temperature resistance
df_coarse["diff_mW"] = df_coarse["Power [mW]"] - df_coarse["I2R_mW"]
df_smooth["diff_mW"] = df_smooth["Power [mW]"] - df_smooth["I2R_mW"]

# Calculate uniform X-axis step intervals to split the scale into exactly 17 tick marks
T_max_c = df_coarse["T [K]"].max()
T_max_s = df_smooth["T [K]"].max()
num_ticks = 17
step_c = max(1, round(T_max_c / (num_ticks - 1)))
xticks_c = np.arange(0, step_c * (num_ticks - 1) + 1, step_c)[:num_ticks]
step_s = max(1, round(T_max_s / (num_ticks - 1)))
xticks_s = np.arange(0, step_s * (num_ticks - 1) + 1, step_s)[:num_ticks]


def fmt_poly(coeffs, var='x'):
    """
    Parses polynomial coefficient arrays from numpy regressions into clean, 
    algebraically correct LaTeX strings for mathematical graph text overlays.
    """
    terms = []
    degree = len(coeffs) - 1
    for i, c in enumerate(coeffs):
        if abs(c) < 1e-12:
            continue
        power = degree - i
        if power == 0:
            term = f"{c:.4g}"
        elif power == 1:
            term = f"{c:.4g}{var}"
        else:
            term = f"{c:.4g}{var}^{power}"
        if i == 0:
            terms.append(term)
        else:
            if c >= 0:
                terms.append(f"+ {term}")
            else:
                if term.startswith('-'):
                    terms.append(f"- {term[1:]}")
                else:
                    terms.append(f"+ {term}")
    return ' '.join(terms)

# Construct a custom proxy legend handle (hollow circle) to define the reference I^2R marks
hollow_handle = Line2D([0], [0], marker='o', color='black', markerfacecolor='none', linestyle='None', markersize=8, label='Ref')

# Plot the coarse current sweep
fig1, (ax_c, ax_cd) = plt.subplots(2, 1, figsize=(12, 10))

ax_c.set_title(r"Coarse: Measured Power & $I^2$ 1$k\Omega$", fontsize=14)
ax_c.set_xlabel("Temperature [K]", fontsize=14)
ax_c.set_ylabel("Power [mW]", fontsize=14)
ax_c.tick_params(axis="both", which="major", length=8, width=2, labelsize=12, direction="in")
ax_c.set_xticks(xticks_c)

# Simultaneously plot instrument measurements (solid markers) against computed reference values (hollow boundaries)
for current, group in df_coarse.groupby("Current [A]"):
    scatter = ax_c.scatter(group["T [K]"], group["Power [mW]"], label=f"{current*1000:.1f}", s=60)
    color = scatter.get_facecolors()[0]
    ax_c.scatter(group["T [K]"], group["I2R_mW"], facecolors='none', edgecolors=color, s=60)

# Compute a quadratic (2nd-degree polynomial) fit tracing measured power growth as a function of temperature
z_pow_c = np.polyfit(df_coarse["T [K]"], df_coarse["Power [mW]"], 2)
p_pow_c = np.poly1d(z_pow_c)
T_range_c = np.linspace(df_coarse["T [K]"].min(), df_coarse["T [K]"].max(), 200)
ax_c.plot(T_range_c, p_pow_c(T_range_c), 'k--', label='Fit')

# Append the custom reference proxy handle to the standard dynamic legend
handles, labels = ax_c.get_legend_handles_labels()
handles.append(hollow_handle)
ax_c.legend(ncols=2,handles=handles, title="Current [mA]", fontsize=12, title_fontsize=12)

# Format and embed the mathematical regression equation within the layout bounds
eq_top = f"Fit: $y = {fmt_poly(z_pow_c)}$"
ax_c.text(0.05, 0.95, eq_top, transform=ax_c.transAxes, fontsize=11, verticalalignment='top')
ax_c.set_ylim(0, max(df_coarse["Power [mW]"] + 2.5))

ax_cd.set_title("Coarse: Power Difference (Measured − $I^2$ 1$k\Omega$)", fontsize=14)
ax_cd.set_xlabel("Temperature [K]", fontsize=14)
ax_cd.set_ylabel(r"$\Delta$ Power [mW]", fontsize=14)
ax_cd.tick_params(axis="both", which="major", length=8, width=2, labelsize=12, direction="in")
ax_cd.set_xticks(xticks_c)

for current, group in df_coarse.groupby("Current [A]"):
    ax_cd.scatter(group["T [K]"], group["diff_mW"], label=f"{current*1000:.1f}", s=60)

# Compute a quadratic fit tracing the behavior of the isolated delta power drift
z_diff_c = np.polyfit(df_coarse["T [K]"], df_coarse["diff_mW"], 2)
p_diff_c = np.poly1d(z_diff_c)
ax_cd.plot(T_range_c, p_diff_c(T_range_c), 'k--', label='Fit')

eq_bot = f"Fit: $y = {fmt_poly(z_diff_c)}$"
ax_cd.text(0.05, 0.95, eq_bot, transform=ax_cd.transAxes, fontsize=11, verticalalignment='top')

ax_cd.legend(ncols=2, title="Current [mA]", fontsize=12, title_fontsize=12)
ax_cd.set_ylim(0, max(df_coarse["diff_mW"] + 0.5))

plt.tight_layout()
fig1.savefig("Thermal_load_coarse.pdf", dpi=150, format="pdf")



# Plot smooth current sweep

fig2, (ax_s, ax_sd) = plt.subplots(2, 1, figsize=(12, 10))

ax_s.set_title(r"Smooth: Measured Power & $I^2$ 1$k\Omega$", fontsize=14)
ax_s.set_xlabel("Temperature [K]", fontsize=14)
ax_s.set_ylabel("Power [mW]", fontsize=14)
ax_s.tick_params(axis="both", which="major", length=8, width=2, labelsize=12, direction="in")
ax_s.set_xticks(xticks_s)

# Replicate overlay strategy (solid measurements vs hollow calculations) for the smooth dataset
for current, group in df_smooth.groupby("Current [A]"):
    scatter = ax_s.scatter(group["T [K]"], group["Power [mW]"], label=f"{current*1000:.1f}", s=60)
    color = scatter.get_facecolors()[0]
    ax_s.scatter(group["T [K]"], group["I2R_mW"], facecolors='none', edgecolors=color, s=60)

# Compute quadratic total power regression for the high-resolution run
z_pow_s = np.polyfit(df_smooth["T [K]"], df_smooth["Power [mW]"], 2)
p_pow_s = np.poly1d(z_pow_s)
T_range_s = np.linspace(df_smooth["T [K]"].min(), df_smooth["T [K]"].max(), 200)
ax_s.plot(T_range_s, p_pow_s(T_range_s), 'k--', label='Fit')

handles, labels = ax_s.get_legend_handles_labels()
handles.append(hollow_handle)

eq_top_s = f"Fit: $y = {fmt_poly(z_pow_s)}$"
ax_s.text(0.05, 0.95, eq_top_s, transform=ax_s.transAxes, fontsize=11, verticalalignment='top')

ax_s.legend(ncols=2, handles=handles, title="Current [mA]", fontsize=12, title_fontsize=12)
ax_s.set_ylim(0, max(df_smooth["Power [mW]"] + 2.5))
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
